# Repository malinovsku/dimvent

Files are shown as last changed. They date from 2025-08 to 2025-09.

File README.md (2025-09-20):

# 🪟 Dimvent ESPHome

**Умный привод для автоматизации окон** на основе мотор-редуктора с прошивкой ESPHome. 

## ✨ Возможности

- **🎯 Точное позиционирование** - Магнитный датчик AS5600 отслеживает положение рычага
- **🛡️ Защита от преград** - Датчик тока INA226 обнаруживает препятствия и автоматически предпринимаются повторные попытки с возвратом на исходное
- **🤖 Автономная работа** - Локальное управление ESPHome и Home Assistant

## 🛒 Компоненты

| Название | Ссылка | Описание |
| :--- | :--- | :--- |
| Мотор-редуктор 12V 6RPM | [Ozon](https://ozon.ru/t/GNIRneC) | Силовой привод с двумя валами |
| AS5600 + магнит | [Ali](https://aliexpress.ru/item/1005008249897817.html) | Магнитный энкодер для точного позиционирования |
| INA226 | [Ali](https://aliexpress.ru/item/1005006369070438.html) | Датчик тока и напряжения для защиты |
| Mini360 | [Ali](https://aliexpress.ru/item/1005008400769897.html) | Понижающий DC-DC преобразователь |
| DRV8871 | [Ali](https://aliexpress.ru/order-list/5549620160767253) | Драйвер двигателя с поддержкой PWM |
| Диод |-| Диод для установки после понижающего 5в |
| Шары для крепления | [AliExpress](https://sl.aliexpress.ru/p?key=77D9GlK) | Шарнирное соединение для тяги |
| Фланцевая муфта 6мм | [Ali](https://aliexpress.ru/item/1005006306920922.html) | Соединитель вала с рычагом |
| Винт м3х6 (3шт)| [Ali](https://aliexpress.ru/item/1005004567542471.html) |Крепление мотора к корпусу |
| Винт м3х6 (4шт) плоская шляпка|-|Крепление муфты к рычагу |
| ESP32-C3/S3 | - | Мозг системы на ESPHome |
| Печатная плата 3х7 см | [Ozon](https://www.ozon.ru/product/pechatnaya-maketnaya-plata-3x7-sm-dvuhstoronnyaya-dlya-payki-gsmin-pcb1-10-shtuk-zelenyy-1220449711/) | Кастомная монтажная плата |
| Клеммы винтовые 2pin | - | Клеммы для подключения питания |
| WS2812 (1шт) | - | Светодиод для информмирования. Опционально |
| Кнопки (2шт) | [Ali](https://aliexpress.ru/item/4000245786194.html) | Кнопки открытия/закрытия |

## 🛠️ Сборка устройства

### 🗺️Схема подключения

<p align="center">
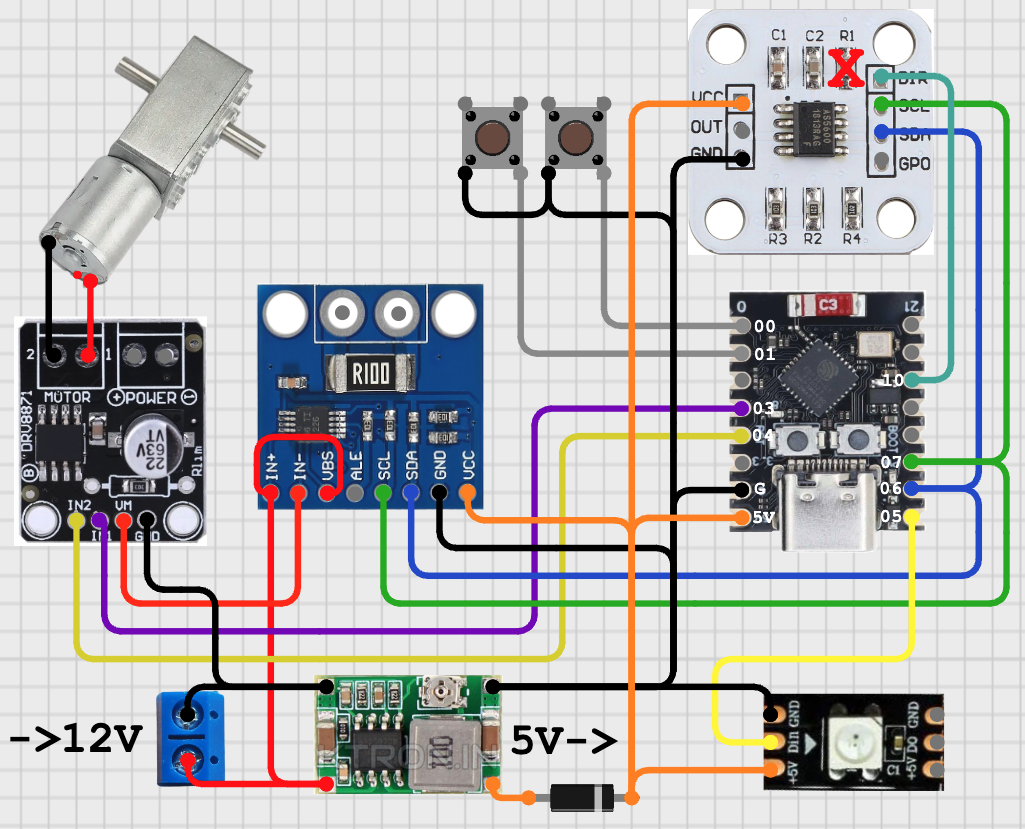
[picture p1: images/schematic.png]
Электрическая схема
    
</p>

### 📟Сборка платы

Плата собирается на макетной плате 3x7 см с соблюдением особых условий:
> - Надпись `30х70мм` должна находится у основания
> - Требуется изоляция под контактами AS5600 (VCC/OUT/GND) для предотвращения КЗ(например каптоновый скотч). **Резистор R1 выкусить/выпаять**
> - На Mini360 выставить 5в через диод (необходим для защиты одновременного включения БП и USB)

<p align="center">
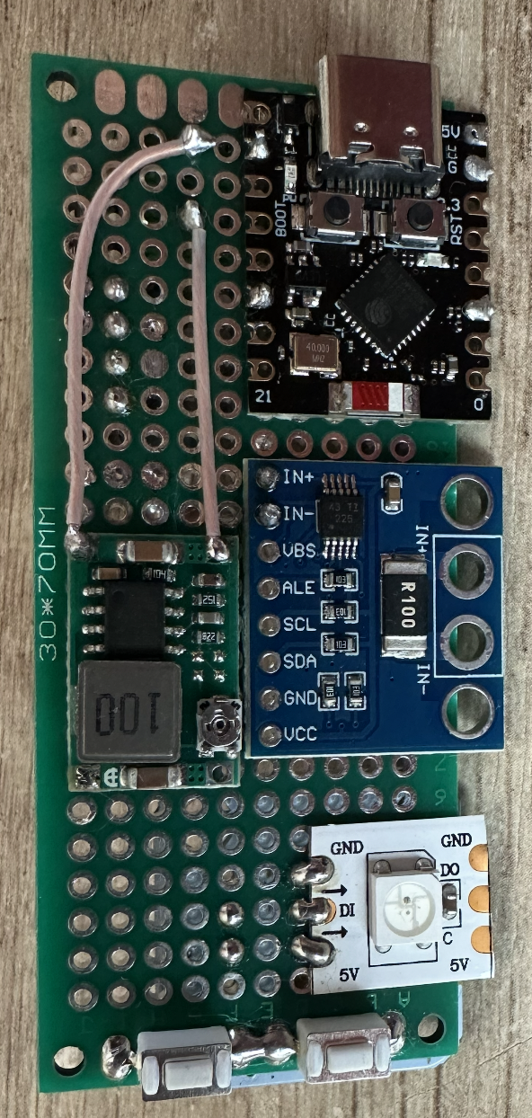
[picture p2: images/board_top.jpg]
Верх платы
  
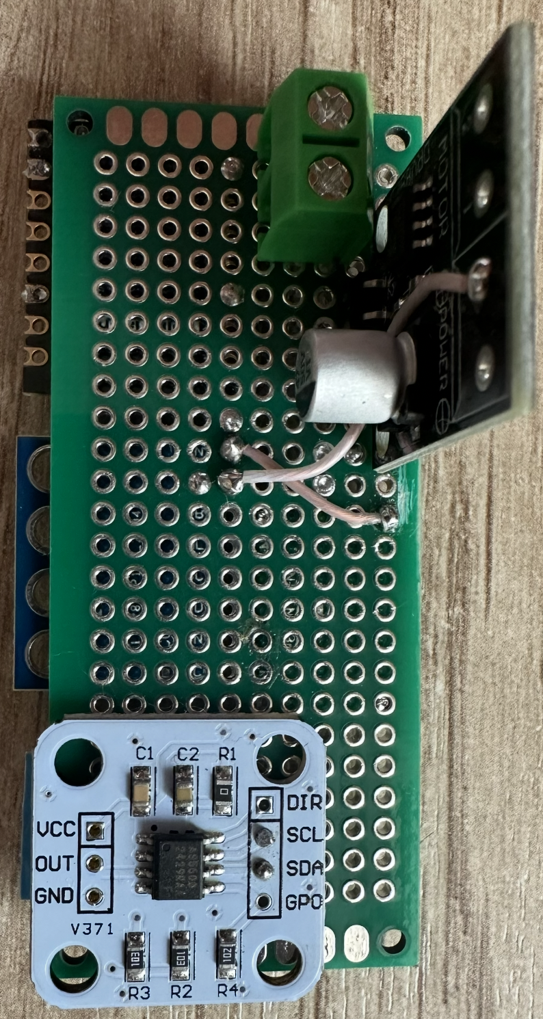
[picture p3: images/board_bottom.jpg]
Низ платы
  
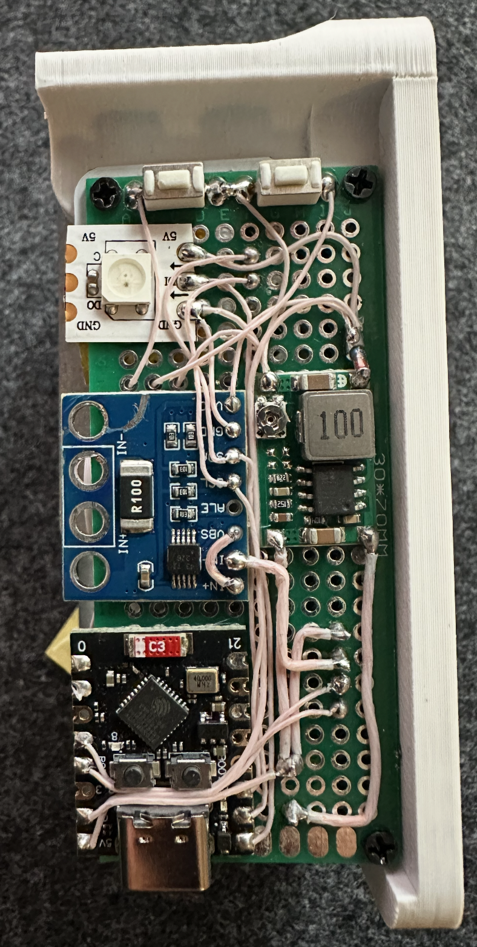
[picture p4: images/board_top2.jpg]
Верх платы 2
  
</p>

### 🚀 3D модели и сборка

Модели для печати в папке `models`.

Настройки печати:
- ABS
- 100% заполнением
> - Для регулировки длины тяги - продублируйте модель в слайсере и установите необходимую длину

### ⚖️Калибровка магнита и сенсора AS5600
> - Подключите устройство к питанию
> - Проверьте что кнопки `Motor clockwise` `Motor counterclockwise` `Motor Stop` работают корреткно и отрегулируйте вал в положение что бы фаска смотрела в сторону мотора, это закрытое положение и рычаг в итоге в таком положении должен быть как на фото ниже.
> - Магнит на валу откалибруйте руками в положении ~90° по сенсору **Angle** и зафиксируйте пластик с магнитом на валу.

Если кнопки `Motor clockwise` `Motor counterclockwise` работают наоборот, то вы ошиблись в пайкой, перепаяйте или измените местами **pin_output_1** и **pin_output_2**
<p align="center">
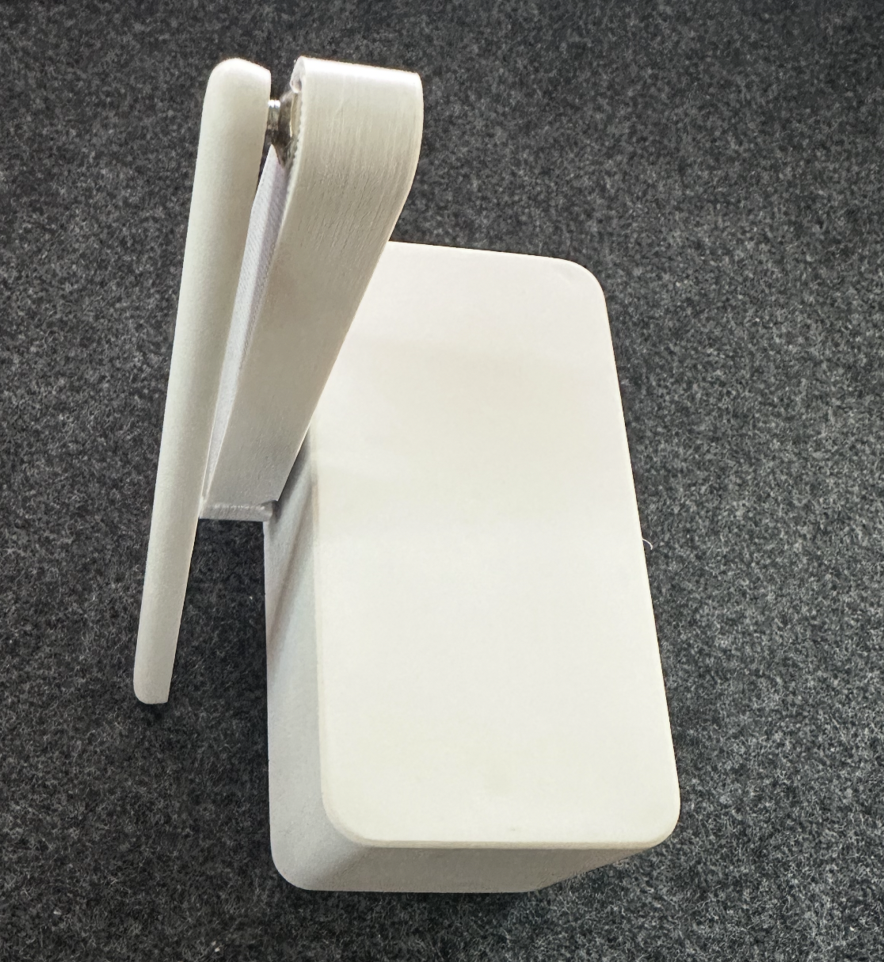
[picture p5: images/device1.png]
    
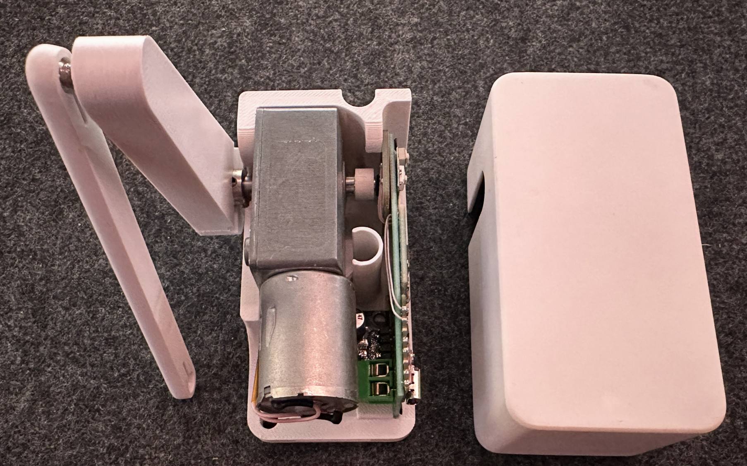
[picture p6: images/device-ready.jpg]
    
</p>

## 🎮 Прошивка и настройка

Основной конфигурационный файл: **[`dimvent.yaml`](dimvent.yaml)**

В файле в шапке `substitutions` замените свои значения при необходимости.

| Объект | Описание |
| :--- | :--- |
| **Window** | Основной объект для управления окном (открыть/закрыть/остановить) |
| **Angle** | Текущий угол поворота вала в градусах |
| **Position** | Положение окна в процентах (0% - закрыто, 100% - открыто) |
| **Power** | Мониторинг потребляемой мощности мотора |
| **Unsuccessful attempts** | Счетчик неудачных попыток движения |
| **Attempts exceeded** | Индикатор критической ошибки |
| **Angle Closed Position** | Настройка калибровки положения "Закрыто" |
| **Limit Closed +** | Ограничение тока для закрытия на разных скоростях |
| **Limit Open +** | Ограничение тока для открытия на разных скоростях |
| **Number repeat attempts** | Настройка количества автоматических попыток |
| **Fix problem** | Кнопка сброса ошибок |
| **Motor clockwise** | Ручное управление: вращение по часовой |
| **Motor counterclockwise** | Ручное управление: вращение против часовой |
| **Motor Stop** | Аварийная остановка двигателя |
| **Speed** | Выбор скорости работы (High/Medium/Low) |
| **Angle Opening** | Угол открытия относительно закрытого положения 0-180 |
| **Forced power increase** | Принудительное увеличении мощности\скорости при нехватке мощности, неподвижность вала (High/Medium/Step/OFF) |

## 💡 Финальная настройка

- Откалибруйте **Angle Closed Position** после установки на окно
- Выставите в **Number repeat attempts** необходимое количество попыток
- Настройте **Limit Open/Closed** под конкретное окно для оптимальной работы
- Используйте **Speed** для баланса между скоростью и мощностью
- Выставите в **Forced power increase** принудительное увеличение мощности перед повторами при не хватке мощности, постепенное - `Step`, на скорость - `High\Medium`, выключено - `OFF`.

---

**⭐ Нравится проект? Не забудьте поставить звезду на GitHub!**

---

The firmware source code in this repository is licensed under GPLv3. The hardware design files (schematics, 3d models) and documentation are licensed under Creative Commons Attribution-NonCommercial-ShareAlike 4.0 International (CC BY-NC-SA 4.0).

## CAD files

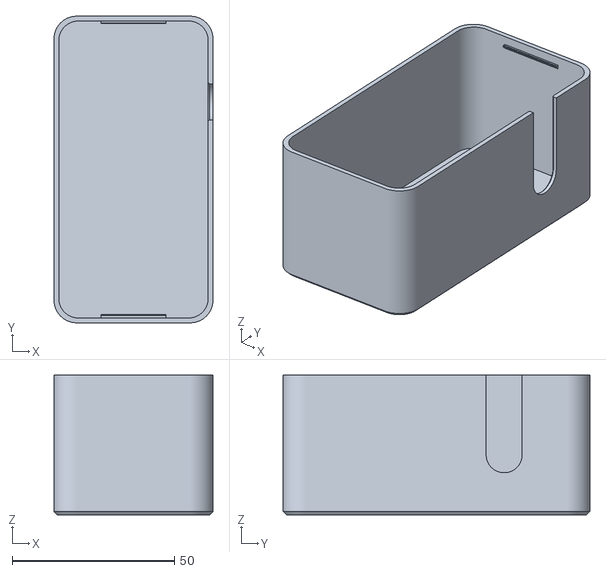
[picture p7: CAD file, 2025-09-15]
models/Крышка без кнопок.stl
49.0 x 94.5 x 43.0

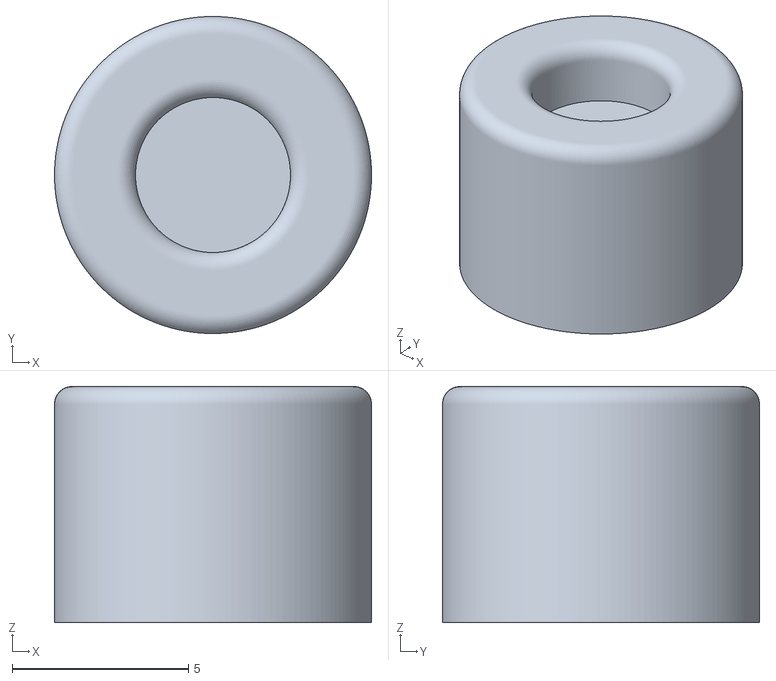
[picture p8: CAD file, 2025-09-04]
models/Крепление магнита на вал.stl
9.00 x 9.00 x 6.70

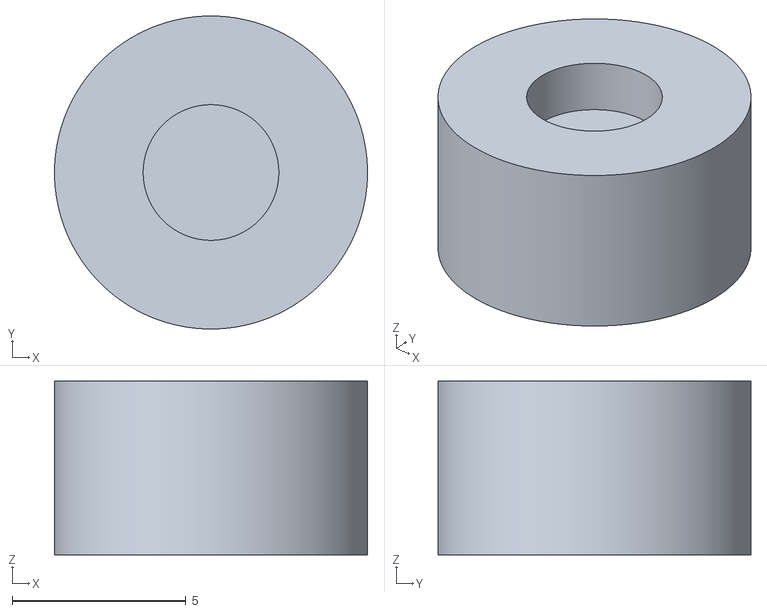
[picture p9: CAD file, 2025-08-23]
models/Держатель магнита.stl
9.00 x 9.00 x 5.00

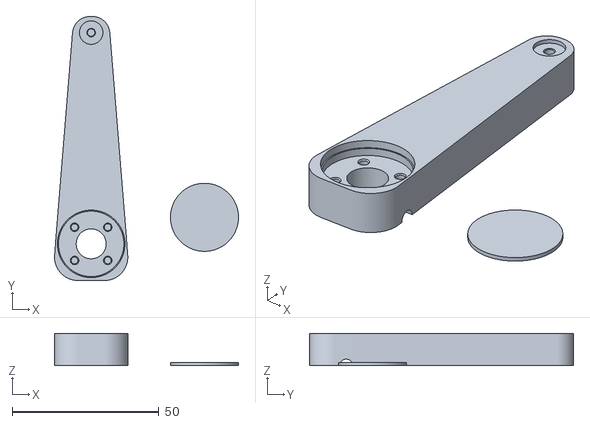
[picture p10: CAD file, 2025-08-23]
models/Рычаг.stl
62.7 x 90.0 x 11.0

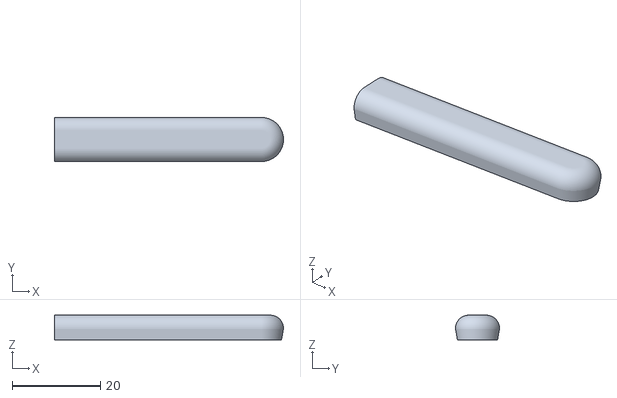
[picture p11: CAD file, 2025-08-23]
models/Тяга.stl
52.0 x 10.0 x 5.60

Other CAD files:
models/Крышка с кнопками.stl

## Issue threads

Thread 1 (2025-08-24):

Failed config. light.esp32_rmt_led_strip

alleonname, 2025-08-24:
INFO ESPHome 2025.5.0
INFO Reading configuration /config/esphome/dimvent.yaml...
Failed config

light.esp32_rmt_led_strip: [source /config/esphome/dimvent.yaml:311]

  rmt_channel is a required option for the Arduino framework.

malinovsku, 2025-09-04:
@alleonname в light добавить rmt_channel: 0

Closed 2025-09-04.

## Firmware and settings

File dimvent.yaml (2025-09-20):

# https://github.com/malinovsku/dimvent
substitutions:
  device_name: dimvent
  friendly_name: Dimvent
  project: "malinovsku.Dimvent"
  name_add_mac_suffix: "false"

  wifi_ssid: !secret wifi_ssid
  wifi_password: !secret wifi_password
  ap_wifi_password: !secret wifi_ap_pass
  api_key: !secret api_key
  ota_password: !secret ota_password

  speed_high: 1.0
  speed_medium: 0.8
  speed_low: 0.68
  time_check_spin: 1100ms # Интервал проверки угла
  time_stoped_motor: 1s # Время остановки мотора
  direction: clockwise

  pin_output_1: GPIO03
  pin_output_2: GPIO04
  pin_light: GPIO05
  pin_dir: GPIO010
  pin_sda: GPIO06
  pin_scl: GPIO07
  pin_button_1: GPIO00
  pin_button_2: GPIO01

api:
  encryption:
    key: ${api_key}

ota:
  - platform: esphome
    password: ${ota_password}

wifi:
  ssid: ${wifi_ssid}
  password: ${wifi_password}
  ap:
    ssid: ${device_name}
    password: ${ap_wifi_password}

esp32:
  board: esp32-c3-devkitm-1
  framework:
    type: arduino

esphome:
  name: ${device_name}
  friendly_name: ${friendly_name}
  name_add_mac_suffix: ${name_add_mac_suffix}
  project:
    name: ${project}
    version: ${device_name}
  comment: ${project}
  on_boot:
    priority: -800
    then:
      - button.press: fix_problem

captive_portal:

logger:
  level: INFO

web_server:
    port: 80
    version: 3

i2c:
  sda: ${pin_sda}
  scl: ${pin_scl}

as5600:
  start_position: 0deg
  range: 360deg
  id: my_as5600
  dir_pin: ${pin_dir}
  direction: ${direction}

globals:
  - id: g_speed
    type: float
    restore_value: true
  - id: g_speed_latest
    type: float
    initial_value: '0.0'
  - id: position_new
    type: float
    initial_value: '0.0'
  - id: position_latest
    type: float
    initial_value: '0.0'
  - id: gl_check_spin_latest
    type: float
    initial_value: '0.0'

binary_sensor:
  - platform: status
    name: Status esp
    entity_category: diagnostic
  - platform: template
    name: "Attempts exceeded"
    device_class: problem
    id: problem_attempts_exceeded
    on_press:
      then:
        - light.turn_on:
            id: status_light
            brightness: 100%
            red: 100%
            green: 0%
            blue: 0%
            effect: "Fast Pulse"
    on_release:
      then:
        - light.turn_off: status_light
  - platform: gpio
    name: Button1
    disabled_by_default: true
    id: bt1
    filters:
      - delayed_on: 100ms
    pin:
      number: ${pin_button_1}
      mode: INPUT_PULLUP
      inverted: True
    on_press:
      then:
        - if:
            condition:
              - lambda: return id(window).current_operation == CoverOperation::COVER_OPERATION_IDLE;
            then:
              - cover.open: window
            else:
              - cover.stop: window
  - platform: gpio
    name: Button2
    disabled_by_default: true
    id: bt2
    filters:
      - delayed_on: 100ms
    pin:
      number: ${pin_button_2}
      mode: INPUT_PULLUP
      inverted: True
    on_press:
      then:
        - if:
            condition:
              - lambda: return id(window).current_operation == CoverOperation::COVER_OPERATION_IDLE;
            then:
              - cover.close: window
            else:
              - cover.stop: window
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

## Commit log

2025-08-23 Dimvent ESPHome
    [Крышка без кнопок.stl, Крышка с кнопками.stl, Рычаг.stl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]
2025-08-23 удаление лишнего
2025-08-23 добавлена модель и мелкие корректировки прошивки
    [Держатель магнита.stl]
2025-09-20 добавлена логика принудительной увеличении мощности
2025-09-20 правка README
